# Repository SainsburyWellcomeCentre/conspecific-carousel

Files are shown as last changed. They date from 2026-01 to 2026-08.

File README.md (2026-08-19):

# Conspecific Carousel



An automated behavioral apparatus for rat/mice social interaction experiments with rotating arena and multiple nose-poke ports.

Conspecific Carousel System

The Conspecific Carousel is a behavioral testing apparatus designed for rodent social interaction studies. It features a computer-controlled rotating platform (8 positions), automated door mechanism, and three nose-poke ports with beambreak detection, LED cues, and water/reward delivery. The system enables precise control of animal access and position while synchronizing with external recording equipment.

## 🔧 Features

- **8-Position Rotary Table** - Dynamixel servo-driven platform with 45° indexing
- **Automated Door Control** - Dynamixel servo with position feedback for entry/exit control
- **Nose Poke Ports** - Individual LED illumination, valve control, and beambreak detection (Ports A, B, C)
- **Camera Synchronization** - BNC outputs for frame-accurate event timing
- **Modular Beambreak Arrays** - Available in L (large) and S (small) configurations

## 🌐 View Online (eCAD)

View the complete electronic design project online via [Altium 365 Viewer](https://sainsburywellcomecentre.github.io/fablabs-documentation/#conspecific-carousel)

## 🚀 Getting Started

### Hardware Assembly

1. **Assemble PCBs** - Order and assemble all five PCBs (main controller + 4 beambreak arrays) using provided fabrication files
2. **Install Motors** - Mount Dynamixel servos for door and table rotation mechanisms
3. **Connect Sensors** - Wire beambreak arrays to nose poke ports and position sensors to door/table
4. **Power Up** - Connect 12V power supply for motors and USB for control/communication

### Firmware installation

1. **Flash MicroPython** — download the latest RP2354 MicroPython UF2 from [micropython.org](https://micropython.org/download/RPI_PICO2/) and copy it to the board while holding BOOTSEL.
2. **Install mpremote** — `pip install mpremote`
3. **Copy firmware files** — from the `firmware/` directory, copy everything to the board:

   ```bash
   mpremote cp -r firmware/. :
   ```

4. **Install dependencies** — run the following commands to install the required libraries from GitHub:

   ```bash
   mpremote mip install github:SainsburyWellcomeCentre/micropython-dynamixel
   ```

5. **Reset the board** — the device will enumerate as a USB CDC serial port and announce itself.

### Desktop App Control

1. **Install dependencies** - Run `pip install -r requirements.txt` in the `software/` directory
2. **Run app** - Execute `python main.py` to launch the control interface
3. **Connect to device** - Select the serial port and baud in the app settings

```bash
cd software
pip install -r requirements.txt
python main.py
```

## 📡 Communication Protocol

### Register Map

#### System

| Register | Address | Type  | Description |
| --- | --- | ----- | --- |
| LED/Sync | `0x01`  | `R/W` | `0x00`: off, `0x01`: on — controls sync_out/LED |

#### Door

| Register | Address | Type  | Description |
| --- | --- | ----- | --- |
| Door Status | `0x10`  | `R` | `0x00`: closed, `0x01`: opened, `0x02`: moving, `0x03`: paused |
| Door Command | `0x11`  | `W` | `0x00`: open, `0x01`: close, `0x02`: stop |
| Door Open Speed  | `0x12`  | `R/W` | 0-255: open speed (higher = faster) |
| Door Close Speed | `0x13`  | `R/W` | 0-255: close speed (higher = faster) |

#### Table

| Register | Address | Type  | Description |
| --- | --- | ----- | --- |
| Table Status  | `0x18`  | `R` | `0x00`: stopped, `0x01`: moving |
| Table Command | `0x19`  | `W` | bit 7: direction (`0` = CW, `1` = CCW), bits 0–6: position in 1/8-turn units |
| Table Speed | `0x1A`  | `R/W` | 0-255: table movement speed value |

#### Side Sensors

| Register | Address | Type | Description |
| --- | --- | ---- | --- |
| Door Sensor  | `0x02`  | `R`  | `0x00`: no object detected, `0x01`: object detected |
| Table Sensor | `0x03`  | `R`  | `0x00`: no object detected, `0x01`: object detected |

#### Peripherals — Port A / B / C

| Register | Port A | Port B | Port C | Type  | Description |
| --- | --- | --- | --- | ----- | --- |
| LED Status | `0x21` | `0x24` | `0x27` | `R/W` | `0x00`: off, `0x01`: on |
| Valve Status | `0x22` | `0x25` | `0x28` | `R/W` | `0x00`: off, `0x01`: on |
| IR Sensor Status | `0x23` | `0x26` | `0x29` | `R` | `0x00`: no object detected, `0x01`: object detected |

#### Camera

| Register | Address | Type | Description |
| --- | --- | ---- | --- |
| Cam A State | `0x04`  | `R`  | Current Cam A state |
| Cam B State | `0x05`  | `R`  | Current Cam B state |

#### Buzzer

| Register | Address | Type  | Description |
| --- | --- | ----- | --- |
| Buzzer Enable | `0x30`  | `R/W` | `0x00`: disabled, `0x01`: enabled |
| Buzzer Freq | `0x31`  | `R/W` | Frequency value for buzzer (Hz or device-specific units) |

### TX Protocol (Host → Device)

| Byte 3 | Byte 2 | Byte 1 | Byte 0 |
| --- | --- | --- | --- |
| Header | Register | Message Type | Value  |

- **Header**: `0xCC`
- **Register**: Address from the register map
- **Message Type**: `0x01` Write, `0x02` Read
- **Value**: Data to write (ignored for Read)

### RX Protocol (Device → Host)

| Byte 3 | Byte 2 | Byte 1 | Byte 0 |
| --- | --- | --- | --- |
| Header | Register | Message Type | Value  |

- **Header**: `0xCC`
- **Register**: Address of the register being reported
- **Message Type**: `0x02` Acknowledgement, `0x03` Event Notification
- **Value**: Current register value

#### Event Notifications

Events are sent asynchronously by the device when hardware state changes:

| Source | Register | Trigger |
| --- | --- | --- |
| Door | `0x10` | Door status changed |
| Table | `0x18` | Table started/stopped |
| Port A–C IR  | `0x23`–`0x29` | Beambreak triggered/cleared |
| Door Sensor  | `0x02` | Door sensor state changed |
| Table Sensor | `0x03` | Table sensor state changed  |
| Cam A | `0x04` | Cam A state changed |
| Cam B | `0x05` | Cam B state changed |

### Configuration

- TX Buffer Length: 128 bytes
- RX Buffer Length: 128 bytes

## 🖥️ Software Guide

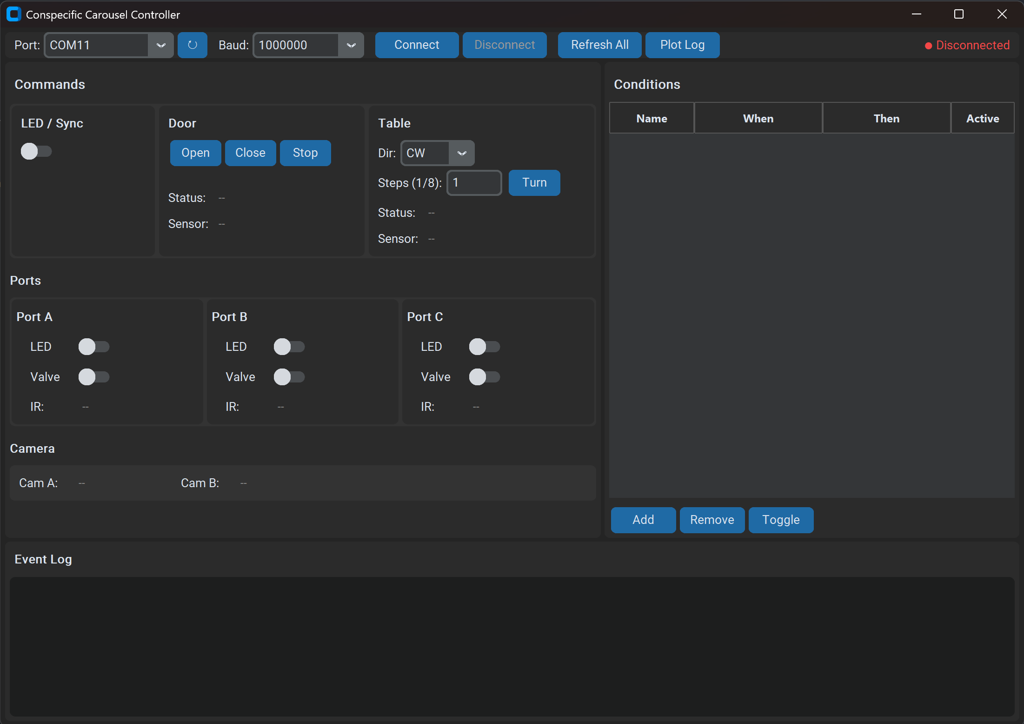
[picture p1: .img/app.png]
Conspecific Carousel app screenshot


1. **Connect to device** — Select the serial port and baud rate in the app settings
2. **Monitor events** — View real-time sensor states and event logs in the app interface
3. **Control hardware** — Use app controls to operate the door, rotate the table, and manage nose poke ports
4. **Log data** — All events are automatically recorded while the app is running, saved in `./log/` with timestamped filenames for later analysis
5. **Integrate with experiments** — Use BNC outputs to synchronize with external recording equipment for precise event timing
6. **Customize conditions** — Define automation rules with AND/OR/NOT logic triggers in the right panel to execute actions based on sensor states

## 💻 Software Requirements

- **Python 3.8+** — Required for running the desktop control app
  - Dependencies: `pyserial`, `customtkinter`, `matplotlib` (see `software/requirements.txt`)
- **MicroPython** — Firmware runtime on the microcontroller

To view or edit the source design files:

- **Altium Designer 20.0+** _(electronic design)_ — Academic licenses via [Altium Education](https://www.altium.com/education)
- **Inventor 2025+** _(mechanical design)_ — Academic licenses via [Autodesk Education](https://www.autodesk.com/education/free-software/inventor)

## 📜 License

**Sainsbury Wellcome Centre hardware is released under** [Creative Commons Attribution-ShareAlike 4.0 International](http://creativecommons.org/licenses/by-sa/4.0/).

You are free to:

- **Share** — copy and redistribute the material in any medium or format
- **Adapt** — remix, transform, and build upon the material for any purpose

Under the following terms:

- **Attribution** — Give appropriate credit, link to the license, and indicate changes.
- **ShareAlike** — Distribute your contributions under the same license.
- **No additional restrictions** — Don't apply legal or technological measures that prevent others from doing anything the license permits.

> For the full legal text, see [LICENSE](LICENSE).

## 📚 References _(if applicable)_

If your research uses this apparatus, please cite:

```bibtex
@misc{ConspecificCarousel2026,
  title     = "Conspecific Carousel: Automated Behavioral Apparatus for Rodent Social Interaction",
  author    = "Sainsbury Wellcome Centre",
  year      = "2026",
  publisher = "GitHub",
  url       = "https://github.com/SainsburyWellcomeCentre/conspecific-carousel"
}
```

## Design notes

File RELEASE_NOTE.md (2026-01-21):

# Release Notes

**Rat Social Box Extension:** v1.0  
**Beambreak Array L - Emitter:** v1.0  
**Beambreak Array L - Receiver:** v1.0  
**Beambreak Array S - Emitter:** v1.0  
**Beambreak Array S - Receiver:** v1.0  
**Firmware Version:** v1.0

## 🔧 Key Changes

- Initial release of Conspecific Carousel system
- Integrated door control with Dynamixel servo
- Rotary table with 45° indexing (8 positions)
- Three-port nose poke array with beambreak detection
- Camera synchronization outputs
- USB serial communication protocol
- MicroPython-based firmware with async event handling

## 🛠️ Assembly Instructions

### BOM List

Refer to individual PCB assembly files in each eCAD subfolder:

- [Rat Social Box Extension BOM](eCAD/Rat%20Social%20Box%20Extension/)
- [Beambreak Array L - Emitter BOM](eCAD/Beambreak%20Array%20L%20-%20Emmiter/)
- [Beambreak Array L - Receiver BOM](eCAD/Beambreak%20Array%20L%20-%20Receiver/)
- [Beambreak Array S - Emitter BOM](eCAD/Beambreak%20Array%20S%20-%20Emmiter/)
- [Beambreak Array S - Receiver BOM](eCAD/Beambreak%20Array%20S%20-%20Receiver/)

### Get the PCBA

- **PCBA**: Order from [JLCPCB](https://jlcpcb.com/) (includes assembly service). Refer to the Bill of Materials (BOM) in each PCB's Assembly folder for manual assembly.
- **3D Prints**: _(If applicable)_ Print mechanical components using any 3D printing service.

See the [JLCPCB Assembly Tutorial](https://github.com/SainsburyWellcomeCentre/fablabs-documentation/blob/master/jlcpcb_ordering.md) for step-by-step instructions.

### PCB Fabrication Parameters

**Rat Social Box Extension:**

| Parameter | Value |
| --- | --- |
| Layer Count | 2 |
| Dimensions | 100mm x 80mm |
| Delivery Format | Panel by JLCPCB |
| PCB Thickness | 1.6mm |
| Material Type | FR4 TG130 |
| Surface Finish | ENIG |
| Gold Thickness | 2U" |
| Outer Copper Weight | 1oz |
| Inner Copper Weight | N/A |
| Specify Stackup | N/A |
| Impedance Control | N/A |
| Via Covering | Tented |
| Min via hole size/diameter | 0.3mm |
| Board Outline Tolerance | ±0.2mm |
| Mark on PCB | Remove Mark |

**Beambreak Array L - Emitter:**

| Parameter | Value |
| --- | --- |
| Layer Count | 2 |
| Dimensions | 50mm x 20mm |
| Delivery Format | Panel by JLCPCB |
| PCB Thickness | 1.6mm |
| Material Type | FR4 TG130 |
| Surface Finish | ENIG |
| Gold Thickness | 2U" |
| Outer Copper Weight | 1oz |
| Inner Copper Weight | N/A |
| Specify Stackup | N/A |
| Impedance Control | N/A |
| Via Covering | Tented |
| Min via hole size/diameter | 0.3mm |
| Board Outline Tolerance | ±0.2mm |
| Mark on PCB | Remove Mark |

**Beambreak Array L - Receiver:**

| Parameter | Value |
| --- | --- |
| Layer Count | 2 |
| Dimensions | 50mm x 20mm |
| Delivery Format | Panel by JLCPCB |
| PCB Thickness | 1.6mm |
| Material Type | FR4 TG130 |
| Surface Finish | ENIG |
| Gold Thickness | 2U" |
| Outer Copper Weight | 1oz |
| Inner Copper Weight | N/A |
| Specify Stackup | N/A |
| Impedance Control | N/A |
| Via Covering | Tented |
| Min via hole size/diameter | 0.3mm |
| Board Outline Tolerance | ±0.2mm |
| Mark on PCB | Remove Mark |

**Beambreak Array S - Emitter:**

| Parameter | Value |
| --- | --- |
| Layer Count | 2 |
| Dimensions | 30mm x 10mm |
| Delivery Format | Panel by JLCPCB |
| PCB Thickness | 1.6mm |
| Material Type | FR4 TG130 |
| Surface Finish | ENIG |
| Gold Thickness | 2U" |
| Outer Copper Weight | 1oz |
| Inner Copper Weight | N/A |
| Specify Stackup | N/A |
| Impedance Control | N/A |
| Via Covering | Tented |
| Min via hole size/diameter | 0.3mm |
| Board Outline Tolerance | ±0.2mm |
| Mark on PCB | Remove Mark |

**Beambreak Array S - Receiver:**

| Parameter | Value |
| --- | --- |
| Layer Count | 2 |
| Dimensions | 30mm x 10mm |
| Delivery Format | Panel by JLCPCB |
| PCB Thickness | 1.6mm |
| Material Type | FR4 TG130 |
| Surface Finish | ENIG |
| Gold Thickness | 2U" |
| Outer Copper Weight | 1oz |
| Inner Copper Weight | N/A |
| Specify Stackup | N/A |
| Impedance Control | N/A |
| Via Covering | Tented |
| Min via hole size/diameter | 0.3mm |
| Board Outline Tolerance | ±0.2mm |
| Mark on PCB | Remove Mark |

### Assembly & Installation

1. Assemble the Rat Social Box Extension PCB first, as it is the main control board.
2. Connect the Dynamixel servo to the designated header on the Rat Social Box Extension.
3. Assemble the Beambreak Array PCBs next. Ensure correct orientation of the IR emitters and receivers.
4. Connect the Beambreak Arrays to the Rat Social Box Extension using the provided connectors.
5. Install the rotary table onto the Rat Social Box Extension, ensuring it can rotate freely.
6. Attach the camera module to the designated mount, if applicable.
7. Finally, enclose the assembly in the provided casing, ensuring all components are securely fitted.

   Use `drill-template].dxf` or refer to the manual dimensions below:

   <p align="center">
       [Assembly Description]
   </p>

8. Test the assembly by powering on the Rat Social Box Extension and checking for correct operation of the servo, beambreak arrays, and rotary table.

## ⚙️ Configuration & Tuning _(if applicable)_

- Configure the USB serial settings to match the host computer.
- Calibrate the beambreak arrays by adjusting the sensitivity settings in the firmware.
- Test the camera synchronization output with the connected camera system.

## 🔧 [Configuration/Calibration] Guidelines

- Adjust the Dynamixel servo ID and baud rate in the firmware to match your specific servo model.
- Fine-tune the rotary table indexing by modifying the stepper motor parameters in the firmware.
- Set the correct number of positions (8 for 45° indexing) in the firmware configuration.

<div align="center">
  [Configuration Description]
</div>

## 💻 Firmware Upload _(if applicable)_

1. Connect the Rat Social Box Extension to your computer via USB.
2. Put the device in firmware upload mode by connecting the designated boot pins.
3. Use a compatible flashing tool (e.g., `esptool.py` for ESP32) to upload the firmware binary.
4. Monitor the upload process for any errors.
5. Once completed, disconnect and reconnect the device to exit boot mode.

## 📁 Attachement

```bash
├── Rat Social Box Extension.zip                    # Electronic CAD files
│   ├── Assembly/
│   │   ├── BOM.xlsx         # Bill of Materials
│   │   └── pick and place.csv
│   ├── Drawing/
│   │   ├── 2d.dxf          # 2D technical drawings
│   │   └── 3d.step         # 3D models
│   ├── Fabrication/
│   │   ├── Gerber/         # PCB fabrication files
│   │   └── NC Drill/       # Drill files
├── Beambreak Array L - Emitter.zip                    # Electronic CAD files
│   ├── Assembly/
│   │   ├── BOM.xlsx         # Bill of Materials
│   │   └── pick and place.csv
│   ├── Drawing/
│   │   ├── 2d.dxf          # 2D technical drawings
│   │   └── 3d.step         # 3D models
│   ├── Fabrication/
│   │   ├── Gerber/         # PCB fabrication files
│   │   └── NC Drill/       # Drill files
├── Beambreak Array L - Receiver.zip                    # Electronic CAD files
│   ├── Assembly/
│   │   ├── BOM.xlsx         # Bill of Materials
│   │   └── pick and place.csv
│   ├── Drawing/
│   │   ├── 2d.dxf          # 2D technical drawings
│   │   └── 3d.step         # 3D models
│   ├── Fabrication/
│   │   ├── Gerber/         # PCB fabrication files
│   │   └── NC Drill/       # Drill files
├── Beambreak Array S - Emitter.zip                    # Electronic CAD files
│   ├── Assembly/
│   │   ├── BOM.xlsx         # Bill of Materials
│   │   └── pick and place.csv
│   ├── Drawing/
│   │   ├── 2d.dxf          # 2D technical drawings
│   │   └── 3d.step         # 3D models
│   ├── Fabrication/
│   │   ├── Gerber/         # PCB fabrication files
│   │   └── NC Drill/       # Drill files
├── Beambreak Array S - Receiver.zip                    # Electronic CAD files
│   ├── Assembly/
│   │   ├── BOM.xlsx         # Bill of Materials
│   │   └── pick and place.csv
│   ├── Drawing/
│   │   ├── 2d.dxf          # 2D technical drawings
│   │   └── 3d.step         # 3D models
│   ├── Fabrication/
│   │   ├── Gerber/         # PCB fabrication files
│   │   └── NC Drill/       # Drill files
├── 3DP.zip                  # Mechanical CAD files
│   ├── [part1].stl          # 3D printable parts
│   ├── [part2].stl
│   └── [part3].stl
├── Schematic-1.pdf       # Circuit schematic
├── Schematic-2.pdf       # Circuit schematic
├── firmware.[uf2/bin/hex]          # [If applicable] Microcontroller firmware
└── source_code.zip                 # Source design files
```

### `Schematic.pdf`

Contains the complete PCB schematic, drawings, and layer stackup.

### `PCB.zip`

Contains PCB drawings, fabrication outputs, and assembly documentation.

### `3DP.zip`

Contains printable STL models.

### `firmware.[extension]` _(if applicable)_

Contains microcontroller firmware in the appropriate format (.uf2, .bin, .hex, etc.).

### `source_code.zip`

Contains [CAD Software] source files, 3D mechanical designs ([CAD Software]), and firmware source code (C++/MicroPython/Arduino).

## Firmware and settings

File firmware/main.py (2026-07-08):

from hardware import portA, portB, portC, led, door, table, camA, camB, snsr_door, snsr_table, sync_out, buzzer

import asyncio
from utility import WaitAny
from collections import deque
from micropython import const
from table import ONE_EIGHTH


TX_LEN = 128
RX_LEN = 128

HEADER = const(0xCC)
MSG_WRITE = const(0x01)
MSG_READ = const(0x02)
MSG_ACK = const(0x02)
MSG_EVENT = const(0x03)

# Register addresses
REG_LED_SYNC = const(0x01)
REG_DOOR_SENSOR = const(0x02)
REG_TABLE_SENSOR = const(0x03)

REG_CAM_A = const(0x04)
REG_CAM_B = const(0x05)

REG_DOOR_STATUS = const(0x10)
REG_DOOR_CMD = const(0x11)
REG_DOOR_OPN_SPD = const(0x12)
REG_DOOR_CLS_SPD = const(0x13)

REG_TABLE_STATUS = const(0x18)
REG_TABLE_CMD = const(0x19)
REG_TABLE_SPD = const(0x1A)

REG_PA_LED = const(0x21)
REG_PA_VALVE = const(0x22)
REG_PA_IR = const(0x23)
REG_PB_LED = const(0x24)
REG_PB_VALVE = const(0x25)
REG_PB_IR = const(0x26)
REG_PC_LED = const(0x27)
REG_PC_VALVE = const(0x28)
REG_PC_IR = const(0x29)

REG_BZR_EN = const(0x30)
REG_BZR_FREQ = const(0x31)


def _tx_packet(register, msg_type, value):
    return bytes((HEADER, register, msg_type, value))


def _read_register(register):
    if register == REG_LED_SYNC:
        return led.value()
    elif register == REG_DOOR_STATUS:
        return door.status
    elif register == REG_TABLE_STATUS:
        return table.status
    elif register == REG_DOOR_OPN_SPD:
        return door.speed_open
    elif register == REG_DOOR_CLS_SPD:
        return door.speed_close
    elif register == REG_TABLE_SPD:
        return table.speed
    elif register == REG_DOOR_SENSOR:
        return snsr_door.value()
    elif register == REG_TABLE_SENSOR:
        return snsr_table.value()
    elif register == REG_CAM_A:
        return camA.value()
    elif register == REG_CAM_B:
        return camB.value()
    elif register == REG_PA_LED:
        return int(portA.led)
    elif register == REG_PA_VALVE:
        return int(portA.valve)
    elif register == REG_PA_IR:
        return portA.beambreak.value()
    elif register == REG_PB_LED:
        return int(portB.led)
    elif register == REG_PB_VALVE:
        return int(portB.valve)
    elif register == REG_PB_IR:
        return portB.beambreak.value()
    elif register == REG_PC_LED:
        return int(portC.led)
    elif register == REG_PC_VALVE:
        return int(portC.valve)
    elif register == REG_PC_IR:
        return portC.beambreak.value()
    elif register == REG_BZR_EN:
        return buzzer.enabled
    elif register == REG_BZR_FREQ:
        return buzzer.freq
    return 0x00


def _write_register(register, value):
    if register == REG_LED_SYNC:
        sync_out.value(0 if value else 1)
        led.value(value)
    elif register == REG_DOOR_CMD:
        if value == 0x00:
            door.open()
        elif value == 0x01:
            door.close()
        elif value == 0x02:
            door.stop()
    elif register == REG_TABLE_CMD:
        direction = (value >> 7) & 1
        position = value & 0x7F
        table.turn(position * ONE_EIGHTH, dir=direction)
    elif register == REG_DOOR_OPN_SPD:
        door.speed_open = value
    elif register == REG_DOOR_CLS_SPD:
        door.speed_close = value
    elif register == REG_TABLE_SPD:
        table.speed = value
    elif register == REG_PA_LED:
        portA.led = bool(value)
    elif register == REG_PA_VALVE:
        portA.valve = bool(value)
    elif register == REG_PB_LED:
        portB.led = bool(value)
    elif register == REG_PB_VALVE:
        portB.valve = bool(value)
    elif register == REG_PC_LED:
        portC.led = bool(value)
    elif register == REG_PC_VALVE:
        portC.valve = bool(value)
    elif register == REG_BZR_EN:
        buzzer.enabled = bool(value)
    elif register == REG_BZR_FREQ:
        buzzer.freq = value


async def event_monitor(txMessages: deque):
    while True:

        evt = await WaitAny(
            (
                door.isr,
                table.isr,
                portA.beambreak.isr,
                portB.beambreak.isr,
                portC.beambreak.isr,
                camA.isr,
                camB.isr,
                snsr_door.isr,
                snsr_table.isr,
            )
        ).wait()

        if evt is door.isr:
            txMessages.append(_tx_packet(REG_DOOR_STATUS, MSG_EVENT, door.status))
        elif evt is table.isr:
            txMessages.append(_tx_packet(REG_TABLE_STATUS, MSG_EVENT, table.status))
        elif evt is portA.beambreak.isr:
            txMessages.append(_tx_packet(REG_PA_IR, MSG_EVENT, portA.beambreak.value()))
        elif evt is portB.beambreak.isr:
            txMessages.append(_tx_packet(REG_PB_IR, MSG_EVENT, portB.beambreak.value()))
        elif evt is portC.beambreak.isr:
            txMessages.append(_tx_packet(REG_PC_IR, MSG_EVENT, portC.beambreak.value()))
        elif evt is snsr_door.isr:
            txMessages.append(_tx_packet(REG_DOOR_SENSOR, MSG_EVENT, snsr_door.value()))
        elif evt is snsr_table.isr:
            txMessages.append(_tx_packet(REG_TABLE_SENSOR, MSG_EVENT, snsr_table.value()))
        elif evt is camA.isr:
            txMessages.append(_tx_packet(REG_CAM_A, MSG_EVENT, camA.value()))
        elif evt is camB.isr:
            txMessages.append(_tx_packet(REG_CAM_B, MSG_EVENT, camB.value()))
        if evt:
            evt.clear()


async def transceiver(txMessages: deque, rxMessages: deque):

    from usb.device.cdc import CDCInterface
    import usb.device
    stream = CDCInterface(baudrate=1_000_000, timeout=0, txbuf=2048, rxbuf=512)
    usb.device.get().init(stream, builtin_driver=False)

    
    # stream = uselect.poll()
    # stream.register(sys.stdin, uselect.POLLIN)
    while True:
        # Receive 4-byte packets
        
        data = stream.read(4)
        if data and len(data) == 4 and data[0] == HEADER:
            rxMessages.append(data)

        # Send messages
        while txMessages:
            message = txMessages.popleft()
            stream.write(message)

        await asyncio.sleep(0)


async def processor(rxMessages: deque, txMessages: deque):
    while True:
        while rxMessages:
            packet = rxMessages.popleft()
            register = packet[1]
            msg_type = packet[2]
            value = packet[3]

            if msg_type == MSG_WRITE:
                _write_register(register, value)
                txMessages.append(_tx_packet(register, MSG_ACK, _read_register(register)))
            elif msg_type == MSG_READ:
                txMessages.append(_tx_packet(register, MSG_ACK, _read_register(register)))

        await asyncio.sleep(0)


async def main():

    txMessages = deque(bytearray(), TX_LEN)
    rxMessages = deque(bytearray(), RX_LEN)

    monitor_task = asyncio.create_task(event_monitor(txMessages))
    processor_task = asyncio.create_task(processor(rxMessages, txMessages))
    transceiver_task = asyncio.create_task(transceiver(txMessages, rxMessages))

    await asyncio.gather(monitor_task, processor_task, transceiver_task)


asyncio.run(main())

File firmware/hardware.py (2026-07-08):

from machine import Pin, UART
from utility import EventPin
from poke import Poke
from door import RatDoor, MiceDoor
from table import Table
from buzzer import BUZZER

UART_BAUD = 1_000_000  # Baud rate for hardware UART
UART_NUM = 0  # Use UART0
INDICATOR_PIN = 25  # GPIO for indicator LED

RAT_SETTING = True  # Set to True for rat configuration, False for mice configuration

portA = Poke(valve_pin=0, led_pin=3, beambreak_pin=12)
portB = Poke(valve_pin=1, led_pin=4, beambreak_pin=13)
portC = Poke(valve_pin=2, led_pin=5, beambreak_pin=14)

buzzer = BUZZER(pin=7)

camA = EventPin(8, Pin.IN, Pin.PULL_UP)
camB = EventPin(9, Pin.IN, Pin.PULL_UP)

snsr_door = EventPin(26, Pin.IN, Pin.PULL_DOWN)
snsr_table = EventPin(27, Pin.IN, Pin.PULL_DOWN)

sync_out = Pin(10, Pin.OUT, value=1)  # Sync output pin, default high

led = Pin(INDICATOR_PIN, Pin.OUT, value=0)  # Indicator LED

uart = UART(UART_NUM, baudrate=UART_BAUD, tx=Pin(16), rx=Pin(17))  # Adjust pins if needed

if RAT_SETTING:
    door = RatDoor(uart)  # Door configuration for rats
else:
    door = MiceDoor(uart)  # Door configuration for mice

table = Table(uart)

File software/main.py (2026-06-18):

import argparse
import os
import sys
from pathlib import Path


def _run_gui():
    import webview
    from api import WebApp

    def _on_loaded(window, api):
        import json
        api.set_window(window)
        window.evaluate_js(
            f"app.init("
            f"{json.dumps(api.list_task_files())}"
            f")"
        )
        # Do not auto-refresh here; refresh when device actually connects from UI

    api = WebApp()
    html_path = Path(__file__).resolve().parent / "ui" / "index.html"

    window = webview.create_window(
        title="Conspecific Carousel Controller",
        url=html_path.as_uri(),
        js_api=api,
        width=1200,
        height=800,
        min_size=(1000, 650),
    )

    webview.start(func=_on_loaded, args=(window, api), debug=False)
    api.shutdown()


def _run_cli(args):
    from controller import Controller
    from protocol import REGISTER_NAMES, format_value

    ctrl = Controller()
    ctrl.on_error(lambda msg: print(f"ERROR: {msg}", file=sys.stderr))

    print(f"Connecting to {args.port} @ {args.baud} baud …")
    ctrl.connect(args.port, args.baud)
    print("Connected.")

    try:
        executed = False

        if args.status:
            values = ctrl.refresh_all()
            print("\nRegister snapshot:")
            for reg, val in sorted(values.items()):
                name = REGISTER_NAMES.get(reg, f"0x{reg:02X}")
                print(f"  {name:<20} = {format_value(reg, val)}")
            executed = True

        if args.led_sync is not None:
            ctrl.led_sync(bool(args.led_sync))
            print(f"LED/Sync {'On' if args.led_sync else 'Off'}")
            executed = True

        if args.door is not None:
            action = args.door.lower()
            if action == "open":
                ctrl.door_open()
            elif action == "close":
                ctrl.door_close()
            elif action == "stop":
                ctrl.door_stop()
            else:
                print(f"Unknown door action '{args.door}'. Use: open | close | stop",
                      file=sys.stderr)
            print(f"Door: {args.door}")
            executed = True

        if args.table is not None:
            direction, *rest = args.table.split(":")
            steps = int(rest[0]) if rest else 1
            ctrl.table_turn(direction.upper(), steps)
            print(f"Table: {direction.upper()} {steps} step(s)")
            executed = True

        if args.port_led is not None:
            port, val = args.port_led.split(":")
            ctrl.port_led(port, bool(int(val)))
            print(f"Port {port.upper()} LED {'On' if int(val) else 'Off'}")
            executed = True

        if args.port_valve is not None:
            port, val = args.port_valve.split(":")
            ctrl.port_valve(port, bool(int(val)))
            print(f"Port {port.upper()} Valve {'On' if int(val) else 'Off'}")
            executed = True

        if args.write is not None:
            reg, val = [int(x, 0) for x in args.write.split(":")]
            ctrl.write_register(reg, val)
            print(f"Wrote 0x{val:02X} to register 0x{reg:02X}")
            executed = True

        if args.read is not None:
            reg = int(args.read, 0)
            val = ctrl.read_register(reg)
            name = REGISTER_NAMES.get(reg, f"0x{reg:02X}")
            print(f"{name} = {format_value(reg, val)}")
            executed = True

        if not executed:
            print("No action specified. Use --status or a command flag. "
                  "See --help for options.")

    finally:
        ctrl.disconnect()
        ctrl.shutdown()


def _build_parser():
    p = argparse.ArgumentParser(
        prog="main.py",
        description="Conspecific Carousel Controller — GUI or CLI mode.",
        formatter_class=argparse.RawDescriptionHelpFormatter,
        epilog="""
Examples:
  python main.py                              # launch GUI
  python main.py --port COM3 --status         # print register snapshot
  python main.py --port COM3 --led_sync 1     # turn LED/Sync on
  python main.py --port COM3 --door open      # open door
  python main.py --port COM3 --door close
  python main.py --port COM3 --table CW:4     # CW 4/8-turn steps
  python main.py --port COM3 --port_led A:1   # Port A LED on
  python main.py --port COM3 --port_valve B:0 # Port B valve off
  python main.py --port COM3 --write 0x11:0   # raw write reg:value (hex ok)
  python main.py --port COM3 --read 0x10      # raw read register
""",
    )
    p.add_argument("--port",  metavar="PORT",
                   help="Serial port (e.g. COM3 or /dev/ttyUSB0). "
                        "Required for CLI mode; omit to launch the GUI.")
    p.add_argument("--baud",  metavar="BAUD", type=int, default=1_000_000,
                   help="Baud rate (default: 1000000).")
    p.add_argument("--status", action="store_true",
                   help="Print a snapshot of all readable registers.")
    p.add_argument("--led_sync", metavar="0|1", type=int, choices=[0, 1],
                   help="Set LED/Sync output (0=off, 1=on).")
    p.add_argument("--door", metavar="open|close|stop",
                   help="Send a door command.")
    p.add_argument("--table", metavar="DIR[:STEPS]",
                   help="Turn table. DIR=CW|CCW, STEPS=1/8-turn units 1–127 "
                        "(default 1). E.g. CW:4")
    p.add_argument("--port_led", metavar="PORT:0|1",
                   help="Set a port LED. E.g. A:1 or B:0")
    p.add_argument("--port_valve", metavar="PORT:0|1",
                   help="Set a port valve. E.g. A:1 or C:0")
    p.add_argument("--write", metavar="REG:VAL",
                   help="Raw register write (hex or decimal). E.g. 0x11:0x01")
    p.add_argument("--read", metavar="REG",
                   help="Raw register read (hex or decimal). E.g. 0x10")
    return p


if __name__ == "__main__":
    parser = _build_parser()
    args = parser.parse_args()

    if args.port:
        _run_cli(args)
    else:
        _run_gui()

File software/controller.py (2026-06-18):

"""
Controller – public Python API for the Conspecific Carousel device.

Usable without any GUI:

    from controller import Controller

    ctrl = Controller()
    ctrl.connect("COM3", 1000000)
    ctrl.write_register(0x11, 0x00)   # open door
    ctrl.disconnect()
    ctrl.shutdown()

Conditions are stored as individual JSON files in a ``.conditions/`` folder
next to this file.  Task scripts are ``.py`` files in a ``.task/`` folder.
"""

import io
import json
import re
import shutil
import sys
import threading
from contextlib import redirect_stdout, redirect_stderr
from pathlib import Path

from protocol import (
    REGISTER_NAMES,
    READABLE_REGISTERS,
    REG_LED_SYNC,
    REG_DOOR_SENSOR,
    REG_TABLE_SENSOR,
    REG_DOOR_STATUS,
    REG_DOOR_CMD,
    REG_TABLE_STATUS,
    REG_TABLE_CMD,
    REG_PA_LED, REG_PA_VALVE, REG_PA_IR,
    REG_PB_LED, REG_PB_VALVE, REG_PB_IR,
    REG_PC_LED, REG_PC_VALVE, REG_PC_IR,
    MSG_WRITE,
    MSG_ACK,
    MSG_EVENT,
    build_table_command,
    format_value,
    reg_name,
)
from serial_comm import DeviceConnection, list_serial_ports
from csv_logger import CsvLogger
 


_BASE = Path(__file__).resolve().parent
_TASKS_DIR = _BASE / ".task"


def _safe_filename(name: str) -> str:
    """Turn a condition name into a safe filename stem."""
    stem = re.sub(r'[^\w\-]', '_', name).strip('_') or "condition"
    return stem[:64]


class Controller:
    """
    Device controller.  All methods are thread-safe.

    Event callbacks registered via ``on_event``, ``on_ack``, ``on_tx``,
    ``on_error``, and ``on_log`` are called from background threads.
    """

    def __init__(self):
        self._conn: DeviceConnection | None = None
        self._logger = CsvLogger()
        self._lock = threading.Lock()

        self._event_cbs: list = []
        self._ack_cbs: list = []
        self._tx_cbs: list = []
        self._error_cbs: list = []
        self._log_cbs: list = []
        self._task_status_cbs: list = []

        # Ensure tasks folder exists
        _TASKS_DIR.mkdir(exist_ok=True)

    # ------------------------------------------------------------------ #
    #  Callback registration                                             #
    # ------------------------------------------------------------------ #

    def on_event(self, cb):
        """cb(register: int, value: int, formatted: str, reg_name: str)"""
        self._event_cbs.append(cb)

    def on_ack(self, cb):
        """cb(register: int, value: int, formatted: str)"""
        self._ack_cbs.append(cb)

    def on_tx(self, cb):
        """cb(register: int, msg_type: int, value: int)"""
        self._tx_cbs.append(cb)

    def on_error(self, cb):
        """cb(message: str)"""
        self._error_cbs.append(cb)

    def on_log(self, cb):
        """cb(message: str)  — general informational log line."""
        self._log_cbs.append(cb)

    def on_task_status(self, cb):
        """cb(filename: str, status: str)  — 'running' | 'done' | 'error'"""
        self._task_status_cbs.append(cb)

    def _fire(self, cbs, *args):
        for cb in cbs:
            try:
                cb(*args)
            except Exception:
                pass

    def _log(self, msg: str):
        self._fire(self._log_cbs, msg)

    # ------------------------------------------------------------------ #
    #  Ports & connection                                                #
    # ------------------------------------------------------------------ #

    @staticmethod
    def list_ports() -> list[str]:
        return list_serial_ports()

    def connect(self, port: str, baud: int):
        """Connect to the device.  Raises RuntimeError on failure."""
        baud = int(baud)
        with self._lock:
            if self._conn and self._conn.is_connected:
                return
            try:
                conn = DeviceConnection(port, baud)
                conn.on_event(self._handle_event)
                conn.on_ack(self._handle_ack)
                conn.on_tx(self._handle_tx)
                conn.on_error(self._handle_error)
                conn.connect()
                self._conn = conn
            except Exception as e:
                self._conn = None
                raise RuntimeError(str(e)) from e

    def disconnect(self):
        with self._lock:
            if self._conn:
                self._conn.disconnect()
                self._conn = None

    @property
    def is_connected(self) -> bool:
        return bool(self._conn and self._conn.is_connected)

    # ------------------------------------------------------------------ #
    #  Register I/O                                                      #
    # ------------------------------------------------------------------ #

    def write_register(self, register: int, value: int):
        """Blocking write.  Raises RuntimeError if not connected or TimeoutError on no-ACK."""
        if not self.is_connected:
            raise RuntimeError("Not connected.")
        self._conn.write_register(int(register), int(value))

    def read_register(self, register: int) -> int:
        """Blocking read.  Returns the register value."""
        if not self.is_connected:
            raise RuntimeError("Not connected.")
        _, value = self._conn.read_register(int(register))
        return value

    def refresh_all(self) -> dict:
        """Read all readable registers.  Returns {register: value}."""
        result = {}
        for reg in READABLE_REGISTERS:
            try:
                value = self.read_register(reg)
                result[reg] = value
            except Exception:
                pass
        return result

    def send_table_command(self, direction: str, steps: int):
        """Send a table movement command.  direction='CW'|'CCW', steps=1–127."""
        steps = int(steps)
        if not 1 <= steps <= 127:
            raise ValueError("Steps must be between 1 and 127.")
        direction_byte = 0 if direction == "CW" else 1
        self.write_register(REG_TABLE_CMD, build_table_command(direction_byte, steps))

    # ------------------------------------------------------------------ #
    #  Named device wrappers                                             #
    # ------------------------------------------------------------------ #

    def led_sync(self, enable: bool):
        """Turn the LED/Sync output on or off."""
        self.write_register(REG_LED_SYNC, 1 if enable else 0)

    def door_open(self):
        """Send the door-open command."""
        self.write_register(REG_DOOR_CMD, 0x00)

    def door_close(self):
        """Send the door-close command."""
        self.write_register(REG_DOOR_CMD, 0x01)

    def door_stop(self):
        """Send the door-stop command."""
        self.write_register(REG_DOOR_CMD, 0x02)

    def table_turn(self, direction: str, steps: int = 1):
        """Turn the table.  direction='CW'|'CCW', steps=1/8-turn units (1–127)."""
        self.send_table_command(direction, steps)
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

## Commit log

2026-01-20 Enhance event monitoring and command protocol: add camera and sensor support, improve event messages, and update settings
2026-01-21 Add profile_velocity property to Dynamixel class for improved velocity control
2026-01-21 Update README and RELEASE_NOTE: enhance project documentation, add assembly instructions, and detail PCB fabrication parameters
2026-01-22 Refactor Door and Table classes: update initialization parameters, enhance home method, and set current limit for Table motor
2026-02-25 Update Beambreak Array L and S Receiver files: modify PCB and schematic documents
    [Beambreak Array L - Receiver.PcbDoc, Beambreak Array L - Receiver.SchDoc, Beambreak Array S - Receiver.PcbDoc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]
2026-02-25 Refactor door and table control logic: update default lengths, adjust sensor value checks, and enhance command codes in protocol documentation
2026-03-11 Refactor door and table control logic: enhance operation methods, improve interlock handling, and update timeout and velocity settings
2026-03-16 Refactor Door class: adjust closed position for mice setting and update velocity settings for open/close operations
2026-03-19 Update UART baud rate to 1Mbit for improved communication speed
2026-03-19 Refactor WaitAny class: add error handling in wt method to gracefully manage cancelled tasks
    [utility.py]
2026-03-24 Refactor Dynamixel class and related modules: update model handling, improve control table retrieval, and enhance error management
    [table.py]
2026-03-24 Refactor Door and Table classes: streamline task management, enhance error handling, and improve torque control
    [door.py, main.py, table.py]
2026-03-24 added python app for device control
2026-06-02 Refactor main.py: Simplify event handling and remove unused register functions
    - Removed constants and functions related to register communication.
    - Updated event_monitor to send descriptive status messages for door, table, and sensors.
    - Simplified transceiver to handle message reading and writing.
    - Refactored processor to handle new message types and commands directly.
    - Added interlock attribute to Table class in table.py for better control logic.
2026-06-16 Refactor main application to support both GUI and CLI modes
    - Replaced customtkinter GUI with a webview-based interface using HTML, CSS, and JavaScript.
    - Implemented a command-line interface (CLI) for direct control of the system via serial commands.
    - Added a new example task script to flash an LED.
    - Updated requirements to remove customtkinter and include pywebview.
    - Created a new HTML structure for the web interface, including connection management, command controls, and event logging.
    - Introduced a new JavaScript file to handle interactions between the frontend and backend.
    - Added CSS for styling the new web interface.
    [api.py, controller.py, example_no_gui.py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]
2026-06-17 Refactor table control and update door settings
    - Changed the import of `one_eighth` to `ONE_EIGHTH` for consistency.
    - Updated the door initialization to use constants `RAT_SETTING` and `MICE_SETTING`.
    - Refactored the `Table` class to inherit from `Dynamixel` and simplified the initialization.
    - Introduced a `status` property in the `Table` class to replace the `ismoving` attribute.
    - Updated the logic in the `turn` method to use `present_position` instead of `_motor.current_position`.
    - Improved the `_run` method to utilize the new `TOLERANCE` constant and removed unnecessary torque enable/disable methods.
    [door.py, main.py, settings.py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]
2026-06-18 Refactor UI and remove condition management features
    - Removed condition builder UI and related functionality from app.js, index.html, and style.css.
    - Added door open/close speed sliders and buzzer controls to the main interface.
    - Updated protocol.py and app.js to handle new registers for door speeds and buzzer settings.
    - Adjusted layout and styles to accommodate new controls while maintaining responsiveness.
    - Removed unused condition-related code and cleaned up event handling for buzzer frequency.
    [api.py, buzzer.py, controller.py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]
